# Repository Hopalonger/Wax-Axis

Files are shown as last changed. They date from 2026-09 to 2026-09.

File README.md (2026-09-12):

# Wax Axis

A fully automated IR ski/snowboard waxing machine, built as a college engineering project at Oregon State University. Wax Axis drives an IR waxer along a linear axis at a controlled, repeatable speed and pass count, so hot-waxing no longer depends on a human hand holding steady pressure and pace down the length of a ski or snowboard base.

## Background

This project started as a solution to a real bottleneck: as president of Oregon State's Ski and Snowboard Club, I help run free wax nights that typically get through 40–60 pairs of skis and boards in about two hours. Most of that time isn't spent waxing — it's spent scraping — but the waxing step itself is still slow and inconsistent when it's done by hand.
The club had already picked up a Mountainflow IR waxing iron, which works great except that it still has to be dragged across each base by hand at a slow, even pace to get good results. Wax Axis automates that motion.
The machine was originally built out of PVC pipe as a quick, cheap proof of concept, and has since been rebuilt on aluminum 2020 extrusion for rigidity and precision.

## Key Features

- **Automatic frame length detection** — the machine senses the length of the frame/travel automatically rather than requiring a manual endpoint setup
- **Iron speed and pass count control** — set how fast the waxer moves and how many passes it makes per run
- **Automated firmware updates** — OTA updates pushed wirelessly, no need to re-flash by cable
- **Full manual control** — jog and control the axis directly when you don't want an automated run
- **Wireless control via Wi-Fi and a web UI** — control the machine from a phone or laptop browser on the local network, no app required
- **Sensorless homing (StallGuard)** — homes itself using motor stall detection instead of physical limit switches
- **Relay-controlled waxer power** — the IR waxer is switched through a relay rather than staying on a dumb outlet

## Hardware Architecture

- **Frame:** 2020 aluminum extrusion rails with a 2020 gantry carriage (originally prototyped in PVC)
- **Motion:** [PD Stepper](https://www.sparkfun.com/pd-stepper.html) — the core of the whole system. It's an all-in-one, USB-PD-powered NEMA 17 driver/controller with a built-in ESP32-S3, a TMC2209 driver (StallGuard sensorless homing), and an AS5600 magnetic encoder for closed-loop position control — this one board is what handles motion control, homing, and the Wi-Fi/web UI.
- **Drive train:** GT2 10mm timing belt with matching drive and idler pulleys along the extrusion rail
- **Waxer:** IR (infrared) waxer mounted to the carriage as the heat source (purchased separately — a Mountainflow IR iron in this build)
- **I/O expansion:** Qwiic GPIO board over I2C — required for the additional inputs/outputs the project needs beyond the PD Stepper's native pins
- **Power control:** Relay board switches waxer power; power socket, cord, and switch assembly bring mains power into the electronics enclosure
- **Cable management:** Drag chains route wiring along the moving axis to prevent snagging and wear

## Getting Started

1. Assemble the frame from the 2020 extrusion and gantry hardware, and mount the GT2 belt and pulleys along the rail.
2. Wire the electronics enclosure: power entry (socket, cord, switch) → relay board → IR waxer; PD Stepper wired to the motor and belt drive; Qwiic GPIO board connected over the Qwiic/I2C bus.
3. Power on the machine and connect to its Wi-Fi captive portal to join it to your local network.
4. Open the machine's web UI in a browser on that network.
5. Let the machine auto-detect the frame/travel length, or home manually via sensorless homing (StallGuard — no limit switches needed).
6. Set your desired speed and pass count, or switch to full manual control, and run a pass.

## Bill of Materials

Rough parts and pricing for the core electronics/motion system (excludes the IR waxer itself, which is purchased separately — this build uses a Mountainflow IR waxing iron).

| Part | Qty | Link | Rough Price |
|---|---|---|---|
| PD Stepper (ESP32-S3 + TMC2209 + AS5600 closed-loop stepper driver/controller) | 1 | [SparkFun](https://www.sparkfun.com/pd-stepper.html) | $64.95 |
| Qwiic GPIO Board | 1 | [SparkFun](https://www.sparkfun.com/sparkfun-qwiic-gpio.html) | $7 |
| Qwiic Cable (flexible, 500mm) | 1 | [SparkFun](https://www.sparkfun.com/flexible-qwiic-cable-500mm.html) | $3 |
| Relay Board (4-channel, optocoupler isolated) | 1 | [Amazon](https://www.amazon.com/dp/B095YFJ69T) | $7 |
| GT2 Timing Belt, 10mm width, 5m length | 1 | [Amazon](https://www.amazon.com/dp/B078STSGSX) | ~$20 |
| GT2 Drive Pulley, 20T, 5mm bore (10mm belt) | 1+ | [Amazon](https://www.amazon.com/gt2-20t-pulley/s?k=gt2+20t+pulley) | ~$8 |
| GT2 Idler Pulley, 20T toothless, 5mm bore (10mm belt) | 1+ | [Amazon](https://www.amazon.com/gt2-20t-pulley/s?k=gt2+20t+pulley) | ~$8 |
| 2020 Extrusion | 1 | McMaster | $90 |
| Mounting Hardware (fasteners, misc.) | 1 | McMaster | $30 |
| 2020 Gantry Carriage | 1 | [Amazon](https://www.amazon.com/dp/B0DYNV76M3) | $23 |
| Power Socket Plug | 1 | [Amazon](https://www.amazon.com/dp/B0BZR7XDVM) | $9.50 |
| Power Cord | 1 | [Amazon](https://www.amazon.com/dp/B09VRLJD7J) | $6 |
| Power Switch | 1 | [Amazon](https://www.amazon.com/dp/B07RRY5MYZ) | $11 |
| Drag Chains | 1 | McMaster | $110 |

> The core electronics/motion stack (PD Stepper, Qwiic board + cable, relay, belt, and pulleys) comes in around $110–120, in line with the ~$150-in-parts figure for the electronics side of the build, excluding the IR waxer and frame materials.

### Final Design Changes to be made

**Hardware**
- Flip around electronics box plugs, or at least some of them
- Shrink the electronics box
- Update the electronics box to be mounted better
- Create some sort of better lock for the iron to go into — a screw or similar
- Create the final assembly with all of the parts in it

**Software**
- Create a way to manually set endpoints
- Create a way to add in saved speeds with labels for the button, such as "Snowboard," "Ski," "Black Topsheet Ski"

## Status

Active development, working through community and coursework feedback before open-sourcing the full design.

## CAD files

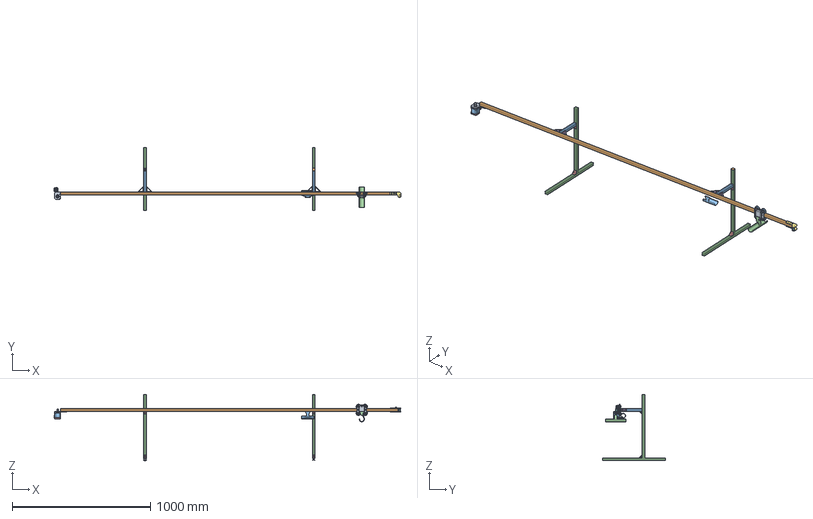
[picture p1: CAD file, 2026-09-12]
Hardware/Main Assembly.step
2506.8 x 457.2 x 479.7 mm
3684N14_Corrosion-Resistant Aluminum Gt Timing Belt Pulley
6627T231_Stepper Motor
3693N13_High-Strength Gt Timing Belt Idler Pulley
Motor Mount
5537T13_T-Slotted Framing
5537T044_T-Slotted Framing x 2
5537T895_T-Slotted Framing_1 x 3
5537T895_T-Slotted Framing
5537T518_T-Slotted Framing
5537T518_T-Slotted Framing_2 x 3
5537T518_T-Slotted Framing_1
5537T658_T-Slotted Framing x 4
Idler Holder Top
Idler Holder Bottom
Bushings
Gantry Plate
Bearing
T-Slot Roller Wheel
Bearing_1
T-Slot Roller Wheel_1
Bushings_1
Bushings_2
Bushings_3
Bearing_2
T-Slot Roller Wheel_2
Bearing_3
T-Slot Roller Wheel_3
91290A434_Black-Oxide Alloy Steel Socket Head Screw
90576A116_Medium-Strength Steel Nylon-Insert Locknut
90576A116_Medium-Strength Steel Nylon-Insert Locknut_1
90576A116_Medium-Strength Steel Nylon-Insert Locknut_2
90576A116_Medium-Strength Steel Nylon-Insert Locknut_3
91290A434_Black-Oxide Alloy Steel Socket Head Screw_1
91290A434_Black-Oxide Alloy Steel Socket Head Screw_2
91290A434_Black-Oxide Alloy Steel Socket Head Screw_3
90128A232_Zinc-Plated Alloy Steel Socket Head Screw
4976N25_T-Slotted Framing Fasteners
Wax Handle Mount V2
5537T14_T-Slotted Framing
Updated IR waxer Hook
Rotated Wax Handle

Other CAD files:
Hardware/Main Assembly.3mf
Hardware/Main Assembly.f3z

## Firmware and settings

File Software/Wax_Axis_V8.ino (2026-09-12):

/*
  Wax Axis V6 (Driver bring-up aligned to known-good V5)

  Fixes:
  - Uses settingsToJsonWithHoming() (exists in homing.h) instead of settingsToJson()
  - Uses waxStartPreheat() / waxStartRun(passes) (exists in wax_process.h)
  - PD CFG mapping + TMC UART setup identical to working V5 patterns
*/

#include <WiFi.h>
#include <ESPAsyncWebServer.h>
#include <AsyncTCP.h>
#include <Preferences.h>
#include <Wire.h>
#include <TMC2209.h>

#include "pins.h"
#include "encoder_as5600.h"
#include "settings.h"
#include "relay_io.h"
#include "motion.h"
#include "homing.h"
#include "wax_process.h"
#include "ota.h"

#include "ui_style.h"
#include "ui_operate.h"
#include "ui_config.h"
#include "ui_settings.h"
#include "ui_update.h"

// ===================== Web Server =====================
AsyncWebServer server(80);

// ===================== Driver =====================
TMC2209 stepper_driver;
HardwareSerial &serial_stream = Serial2;
static const long SERIAL_BAUD_RATE = 115200;

// ===================== Voltage read helpers (MATCH V5) =====================
static float VBusVoltage = 0.0f;
static const float VREF = 3.3f;
static const float DIV_RATIO = 0.1189427313f;

static inline String argOr(AsyncWebServerRequest *request, const char *name, const String &fallback) {
  if (request->hasParam(name, true)) return request->getParam(name, true)->value();
  return fallback;
}
static inline void sendOk(AsyncWebServerRequest *request, const String &msg = "OK") {
  request->send(200, "text/plain; charset=utf-8", msg);
}

// ===================== PD CFG pin mapping (EXACT V5) =====================
static inline void configureVoltagePins() {
  // NOTE: This is NOT binary; keep exactly as V5
  if (gSettings.setVoltage == "5") {
    digitalWrite(CFG1, HIGH);
    digitalWrite(CFG2, LOW);
    digitalWrite(CFG3, LOW);
  } else if (gSettings.setVoltage == "9") {
    digitalWrite(CFG1, LOW);
    digitalWrite(CFG2, LOW);
    digitalWrite(CFG3, LOW);
  } else if (gSettings.setVoltage == "12") {
    digitalWrite(CFG1, LOW);
    digitalWrite(CFG2, LOW);
    digitalWrite(CFG3, HIGH);
  } else if (gSettings.setVoltage == "15") {
    digitalWrite(CFG1, LOW);
    digitalWrite(CFG2, HIGH);
    digitalWrite(CFG3, HIGH);
  } else {  // "20"
    digitalWrite(CFG1, LOW);
    digitalWrite(CFG2, HIGH);
    digitalWrite(CFG3, LOW);
  }
}

static inline void configureDriverFromSettings() {
  // PD output selection
  configureVoltagePins();

  // TMC params
  int ms = gSettings.microsteps.toInt();
  if (ms <= 0) ms = 1;

  stepper_driver.setRunCurrent((uint8_t)gSettings.current.toInt());
  stepper_driver.setMicrostepsPerStep(ms);
  stepper_driver.setStallGuardThreshold((int8_t)gSettings.stallThreshold.toInt());

  // Standstill mode
  if (gSettings.standstillMode == "NORMAL") stepper_driver.setStandstillMode(stepper_driver.NORMAL);
  else if (gSettings.standstillMode == "FREEWHEELING") stepper_driver.setStandstillMode(stepper_driver.FREEWHEELING);
  else if (gSettings.standstillMode == "BRAKING") stepper_driver.setStandstillMode(stepper_driver.BRAKING);
  else if (gSettings.standstillMode == "STRONG_BRAKING") stepper_driver.setStandstillMode(stepper_driver.STRONG_BRAKING);
  else stepper_driver.setStandstillMode(stepper_driver.NORMAL);

  // Motion layer depends on routine speed
  motionSetRoutineSpeedUnits((int)gSettings.routineSpeedUnits);
}

static inline String readPGState() {
  return (digitalRead(PG) == LOW) ? "Power Good" : "Power Bad";
}

static inline String readVoltage() {
  int ADCValue = analogRead(VBUS);
  VBusVoltage = ADCValue * (VREF / 4096.0f) / DIV_RATIO;
  return String(VBusVoltage, 2) + "V";
}

static inline String readEncoderPos() {
  return String(encoderGetCounts());
}

static inline String readTMCStatus() {
  if (stepper_driver.hardwareDisabled()) return "Hardware Disabled";
  TMC2209::Status st = stepper_driver.getStatus();
  if (st.over_temperature_shutdown) return "Over Temp Shutdown";
  if (st.over_temperature_warning) return "Over Temp Warning";
  return "No Errors";
}

void setup() {
  // --------- Pin bring-up (MATCH V5 ordering/levels) ---------
  pinMode(PG, INPUT);

  pinMode(CFG1, OUTPUT);
  pinMode(CFG2, OUTPUT);
  pinMode(CFG3, OUTPUT);

  pinMode(LED1, OUTPUT);
  pinMode(LED2, OUTPUT);

  pinMode(STEP, OUTPUT);
  pinMode(DIR, OUTPUT);
  digitalWrite(STEP, LOW);

  pinMode(MS1, OUTPUT);
  pinMode(MS2, OUTPUT);
  digitalWrite(MS1, LOW);
  digitalWrite(MS2, LOW);

  pinMode(TMC_EN, OUTPUT);
  digitalWrite(TMC_EN, LOW);  // board enable pin (V5)

  pinMode(DIAG, INPUT);
  pinMode(VBUS, INPUT);

  // ADC setup
  analogReadResolution(12);
  analogSetPinAttenuation(VBUS, ADC_11db);

  Serial.begin(115200);
  delay(200);
  Serial.println("\nWax Axis V6 (V5-aligned bring-up) boot...");

  // I2C bus
  Wire.begin(I2C_SDA, I2C_SCL);
  delay(10);

  // Encoder + relay
  encoderBegin();
  bool relayOk = relayBegin();
  Serial.println(relayOk ? "Relay expander OK" : "Relay expander MISSING");
  relaySet(false);

  // Load settings early
  settingsLoad();

  // --------- TMC2209 UART bring-up (EXACT V5 signature) ---------
  stepper_driver.setup(serial_stream, SERIAL_BAUD_RATE, TMC2209::SERIAL_ADDRESS_0, TMC_RX, TMC_TX);
  stepper_driver.enableAutomaticCurrentScaling();
  stepper_driver.enableStealthChop();
  stepper_driver.setCoolStepDurationThreshold(5000);
  stepper_driver.disable();

  // Apply PD voltage + driver params
  configureDriverFromSettings();

  // Motion/homing init
  motionBegin();
  homingLoadState();
  waxStop();

  // WiFi AP
  WiFi.mode(WIFI_AP);
  WiFi.softAP(AP_SSID, AP_PASS);
  Serial.print("AP IP: ");
  Serial.println(WiFi.softAPIP());

  // --------- Pages ---------
  server.on("/", HTTP_GET, [](AsyncWebServerRequest *request) {
    request->send_P(200, "text/html; charset=utf-8", UI_OPERATE_HTML);
  });
  server.on("/setup", HTTP_GET, [](AsyncWebServerRequest *request) {
    request->send_P(200, "text/html; charset=utf-8", UI_CONFIG_HTML);
  });
  server.on("/config", HTTP_GET, [](AsyncWebServerRequest *request) {
    request->send_P(200, "text/html; charset=utf-8", UI_CONFIG_HTML);
  });
  server.on("/settings", HTTP_GET, [](AsyncWebServerRequest *request) {
    request->send_P(200, "text/html; charset=utf-8", UI_SETTINGS_HTML);
  });
  server.on("/update", HTTP_GET, [](AsyncWebServerRequest *request) {
    request->send_P(200, "text/html; charset=utf-8", UI_UPDATE_HTML);
  });
  server.on("/style.css", HTTP_GET, [](AsyncWebServerRequest *request) {
    request->send_P(200, "text/css; charset=utf-8", UI_STYLE_CSS);
  });

  // --------- Stats ---------
  server.on("/powergood", HTTP_GET, [](AsyncWebServerRequest *request) {
    request->send(200, "text/plain; charset=utf-8", readPGState());
  });
  server.on("/voltage", HTTP_GET, [](AsyncWebServerRequest *request) {
    request->send(200, "text/plain; charset=utf-8", readVoltage());
  });
  server.on("/position", HTTP_GET, [](AsyncWebServerRequest *request) {
    request->send(200, "text/plain; charset=utf-8", readEncoderPos());
  });
  server.on("/status", HTTP_GET, [](AsyncWebServerRequest *request) {
    request->send(200, "text/plain; charset=utf-8", readTMCStatus());
  });

  // IMPORTANT: V6 uses this helper (implemented in homing.h)
  server.on("/settingsjson", HTTP_GET, [](AsyncWebServerRequest *request) {
    request->send(200, "application/json; charset=utf-8", settingsToJsonWithHoming());
  });

  server.on("/homingstatus", HTTP_GET, [](AsyncWebServerRequest *request) {
    request->send(200, "application/json; charset=utf-8", homingStatusJson());
  });

  server.on("/waxstatus", HTTP_GET, [](AsyncWebServerRequest *request) {
    request->send(200, "application/json; charset=utf-8", waxStatusJson());
  });

  // --------- Actions ---------
  server.on("/stop", HTTP_POST, [](AsyncWebServerRequest *request) {
    waxStop();
    motionStopAll();
    relaySet(false);
    sendOk(request, "Stopped");
  });

  server.on("/reset", HTTP_POST, [](AsyncWebServerRequest *request) {
    homingCancel();
    waxReset();
    motionStopAll();
    relaySet(false);
    sendOk(request, "Reset complete");
  });

  server.on("/heater", HTTP_POST, [](AsyncWebServerRequest *request) {
    String v = argOr(request, "heater", "");
    if (v.length() == 0) v = argOr(request, "on", "0");
    bool on = (v.toInt() != 0);
    relaySet(on);
    sendOk(request, relayIsOn() ? "Heater ON" : "Heater OFF");
  });

  server.on("/setopspeed", HTTP_POST, [](AsyncWebServerRequest *request) {
    String v = argOr(request, "routinespeed", String((long)gSettings.routineSpeedUnits));
    long rs = v.toInt();
    if (rs < 5) rs = 5;
    if (rs > 200) rs = 200;
    gSettings.routineSpeedUnits = rs;
    settingsSave();
    motionSetRoutineSpeedUnits((int)rs);
    sendOk(request, "OK");
  });

  server.on("/returnhome", HTTP_POST, [](AsyncWebServerRequest *request) {
    waxReturnToParkNow();
    sendOk(request, "Returning to Park");
  });

  server.on("/homing", HTTP_POST, [](AsyncWebServerRequest *request) {
    if (!motionCanAcceptCommand()) {
      request->send(409, "text/plain; charset=utf-8", "Power Bad / Disabled");
      return;
    }
    bool ok = homingStartAsync();
    request->send(200, "application/json; charset=utf-8", ok ? "{\"ok\":true}" : "{\"ok\":false,\"msg\":\"already running\"}");
  });

  // FIX: real function names from wax_process.h
  server.on("/preheat", HTTP_POST, [](AsyncWebServerRequest *request) {
    bool ok = waxStartPreheat();
    request->send(ok ? 200 : 409, "text/plain; charset=utf-8", ok ? "Preheat started" : "Preheat rejected");
  });

  // UI posts: passes=#
  server.on("/run", HTTP_POST, [](AsyncWebServerRequest *request) {
    uint32_t passes = 1;
    if (request->hasParam("passes", true)) passes = (uint32_t)request->getParam("passes", true)->value().toInt();
    if (passes < 1) passes = 1;
    if (passes > 50) passes = 50;  // safety clamp

    bool ok = waxStartRun(passes);
    request->send(ok ? 200 : 409, "text/plain; charset=utf-8", ok ? "Run started" : "Run rejected");
  });

  // Setup page save
  server.on("/save", HTTP_POST, [](AsyncWebServerRequest *request) {
    gSettings.driverEnabled = request->hasParam("enabled1", true);

    gSettings.setVoltage = argOr(request, "setvoltage", gSettings.setVoltage);
    gSettings.microsteps = argOr(request, "microsteps", gSettings.microsteps);
    gSettings.current = argOr(request, "current", gSettings.current);
    gSettings.stallThreshold = argOr(request, "stall_threshold", gSettings.stallThreshold);
    gSettings.standstillMode = argOr(request, "standstill_mode", gSettings.standstillMode);

    gSettings.homingBackoffCounts = argOr(request, "home_backoff", String(gSettings.homingBackoffCounts)).toInt();
    gSettings.gotoTolCounts = argOr(request, "goto_tol", String(gSettings.gotoTolCounts)).toInt();

    settingsSave();
    configureDriverFromSettings();

    request->redirect("/setup");
  });

  // Settings page save (process parameters)
  server.on("/savesettings", HTTP_POST, [](AsyncWebServerRequest *request) {
    // UI provides percent… firmware stores multiplier
    int preheatPct = argOr(request, "preheat_pct", String((int)lroundf(gSettings.preheatMult * 100.0f))).toInt();
    if (preheatPct < 100) preheatPct = 100;
    if (preheatPct > 500) preheatPct = 500;
    gSettings.preheatMult = (float)preheatPct / 100.0f;

    gSettings.returnSpeedPct = argOr(request, "return_pct", String(gSettings.returnSpeedPct)).toInt();
    gSettings.heaterDelayMs = argOr(request, "heater_delay", String(gSettings.heaterDelayMs)).toInt();

    gSettings.edgeKeepoffCounts = argOr(request, "edge_keepoff", String(gSettings.edgeKeepoffCounts)).toInt();
    gSettings.parkOffsetCounts = argOr(request, "park_offset", String(gSettings.parkOffsetCounts)).toInt();
    gSettings.homingSpeedUnits = argOr(request, "homing_speed", String(gSettings.homingSpeedUnits)).toInt();
    gSettings.homingTimeoutMs = (uint32_t)argOr(request, "homing_timeout", String(gSettings.homingTimeoutMs)).toInt();

    String hs = argOr(request, "home_side", gSettings.homeSideIsMin ? "min" : "max");
    gSettings.homeSideIsMin = (hs == "min");

    settingsSave();

    // If we already know ends, recompute park/op window immediately.
    homingRecomputeDerived();

    request->redirect("/settings");
  });
  // OTA
  server.on("/updatefw", HTTP_POST, handleFwUpdateRequest, handleFwUpload);

  server.onNotFound([](AsyncWebServerRequest *request) {
    request->send(404, "text/plain; charset=utf-8", "Not found");
  });


  // ===================== Manual motion controls (Operate page) =====================
  // - slider: signed velocity in UI units (-400..400)
  // - positionControl: 1..4 jog buttons
  server.on("/manual", HTTP_POST, [](AsyncWebServerRequest *request) {
    if (request->hasParam("slider", true)) {
      int v = request->getParam("slider", true)->value().toInt();
      motionSetSlider(v);
    }
    if (request->hasParam("positionControl", true)) {
      int which = request->getParam("positionControl", true)->value().toInt();
      motionJog(which);
    }
    request->send(200, "text/plain", "OK");
  });

  server.on("/goto", HTTP_POST, [](AsyncWebServerRequest *request) {
    if (!request->hasParam("target", true)) {
      request->send(400, "text/plain", "Missing target");
      return;
    }
    long t = request->getParam("target", true)->value().toInt();
    if (!motionCanAcceptCommand()) {
      request->send(409, "text/plain", "Power Bad / Disabled");
      return;
    }
    motionGoto(t);
    request->send(200, "text/plain", "OK");
  });

  server.on("/gotostatus", HTTP_GET, [](AsyncWebServerRequest *request) {
    request->send(200, "text/plain", motionGotoStatus());
  });

  server.begin();

  motionStopAll();
  relaySet(false);

  digitalWrite(LED1, HIGH);
  delay(120);
  digitalWrite(LED1, LOW);

  Serial.println("Wax Axis web server started.");
}

void loop() {
  encoderTask();
  motionEnableTask();
  motionControlTask();
  homingServiceTask();
  waxTask();
}

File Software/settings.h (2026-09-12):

#pragma once
#include <Arduino.h>
#include <Preferences.h>

struct WaxAxisSettings {
  // Driver / low-level
  bool   driverEnabled = true;
  String setVoltage    = "5";     // default to 5V so you can run from laptop USB power
  String microsteps    = "32";
  String current       = "10";
  String stallThreshold= "63";
  String standstillMode= "NORMAL";

  // Motion tolerances (encoder counts)
  long gotoTolCounts   = 3;
  long ppTolCounts     = 6;

  // Homing
  long     homingBackoffCounts = 200;
  long     homingSpeedUnits    = 150;
  uint32_t homingTimeoutMs     = 120000;  // user-adjustable now
  bool     homeSideIsMin       = true;    // min end becomes "home"

  // Rail geometry (user-facing)
  long edgeKeepoffCounts = 800;   // how far from each physical end we operate
  long parkOffsetCounts  = 1000;  // additional offset from the HOME operating edge

  // Operating speed (UI units, 5..200, linear)
  long routineSpeedUnits = 100;

  // Wax routine
  float preheatMult     = 2.0f;
  int   returnSpeedPct  = 200;
  int   heaterDelayMs   = 500;
};

static Preferences gPrefs;
static WaxAxisSettings gSettings;

// Increment this when you change preference semantics/defaults.
static const uint32_t SETTINGS_SCHEMA_VER = 3;

static inline void settingsMigrateIfNeeded() {
  gPrefs.begin("settings", false);

  uint32_t ver = gPrefs.getUInt("schema", 0);
  if (ver < SETTINGS_SCHEMA_VER) {
    // ---- Migration rules ----
    // v2: default PD voltage should be 5V (previous builds often left 20V in NVS).
    // Only force it on migration so users can still change it later.
    gPrefs.putString("voltage", "5");

    // v2: ensure standstill strings are consistent with UI options
    // (UI uses FREEWHEELING; driver mapping accepts both, but keep it neat).
    String ssm = gPrefs.getString("standstillMode", "NORMAL");
    ssm.trim(); ssm.toUpperCase();
    if (ssm == "FREEWHEEL") ssm = "FREEWHEELING";
    gPrefs.putString("standstillMode", ssm);

    // v3: add configurable homing speed default.
    if (ver < 3) {
      gPrefs.putLong("homingSpeed", 150);
    }

    gPrefs.putUInt("schema", SETTINGS_SCHEMA_VER);
  }

  // First-run init (keep separate from schema so we can migrate later)
  bool inited = gPrefs.getBool("init", false);
  if (!inited) {
    gPrefs.putBool("init", true);

    gPrefs.putUInt("schema", SETTINGS_SCHEMA_VER);

    gPrefs.putBool  ("driverEnabled", gSettings.driverEnabled);
    gPrefs.putString("voltage", gSettings.setVoltage);
    gPrefs.putString("microsteps", gSettings.microsteps);
    gPrefs.putString("current", gSettings.current);
    gPrefs.putString("stallThreshold", gSettings.stallThreshold);
    gPrefs.putString("standstillMode", gSettings.standstillMode);

    gPrefs.putLong("gotoTol", gSettings.gotoTolCounts);
    gPrefs.putLong("ppTol", gSettings.ppTolCounts);

    gPrefs.putLong("homeBackoff", gSettings.homingBackoffCounts);
    gPrefs.putLong("homingSpeed", gSettings.homingSpeedUnits);
    gPrefs.putUInt("homeTimeout", gSettings.homingTimeoutMs);
    gPrefs.putBool("homeIsMin", gSettings.homeSideIsMin);

    gPrefs.putLong("edgeKeepoff", gSettings.edgeKeepoffCounts);
    gPrefs.putLong("parkOffset", gSettings.parkOffsetCounts);

    gPrefs.putLong("routineSpeed", gSettings.routineSpeedUnits);

    gPrefs.putFloat("preheatMult", gSettings.preheatMult);
    gPrefs.putInt  ("returnPct", gSettings.returnSpeedPct);
    gPrefs.putInt  ("heaterDelayMs", gSettings.heaterDelayMs);
  }

  gPrefs.end();
}
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

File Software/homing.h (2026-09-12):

#pragma once
#include <Arduino.h>
#include <Preferences.h>
#include <TMC2209.h>

#include "pins.h"
#include "settings.h"
#include "encoder_as5600.h"
#include "motion.h"

// Provided by main .ino
extern TMC2209 stepper_driver;

static Preferences gHomePrefs;

// DIAG behavior (adjust if your DIAG polarity differs)
static const bool DIAG_ACTIVE_HIGH = true;
static const int  DIAG_IRQ_MODE    = RISING;

static volatile bool g_diagHit = false;
static volatile bool g_homeAbort = false;

static inline void IRAM_ATTR diag_isr() {
  g_diagHit = true;
}

static inline void clearDiag() {
  g_diagHit = false;
  (void)digitalRead(DIAG);
}

static inline bool homingAbortRequested() {
  return g_homeAbort;
}


struct HomingState {
  bool running = false;
  bool done    = false;
  bool error   = false;
  String msg   = "idle";

  // physical ends (encoder counts)
  long endMin  = 0;
  long endMax  = 0;

  // derived window + park
  long opMin   = 0;
  long opMax   = 0;
  long parkPos = 0;

  bool validEnds = false;
};

static HomingState gHome;
static portMUX_TYPE gHomeMux = portMUX_INITIALIZER_UNLOCKED;

// ===== Helpers =====
static inline bool diagStable(uint32_t assertMs) {
  static uint32_t sinceMs = 0;
  bool diag = (digitalRead(DIAG) == (DIAG_ACTIVE_HIGH ? HIGH : LOW));
  if (diag) {
    if (sinceMs == 0) sinceMs = millis();
    if (millis() - sinceMs >= assertMs) return true;
  } else {
    sinceMs = 0;
  }
  return false;
}

static inline int32_t rampVelToward(int32_t vNow, int32_t vTarget, int32_t dvMaxPerTick) {
  if (vTarget > vNow) {
    int32_t d = vTarget - vNow;
    if (d > dvMaxPerTick) d = dvMaxPerTick;
    return vNow + d;
  } else {
    int32_t d = vNow - vTarget;
    if (d > dvMaxPerTick) d = dvMaxPerTick;
    return vNow - d;
  }
}

static bool runUntilDiagVelRamped(int32_t vTargetUnits,
                                 uint32_t timeoutMs,
                                 uint32_t diagAssertMs,
                                 int32_t rampUnitsPerTick,
                                 uint32_t tickMs)
{
  clearDiag();
  int32_t vNow = 0;
  stepper_driver.moveAtVelocity(unitsToDriverVel(0));

  const uint32_t STALL_WINDOW_MS = 250;
  const long STALL_MIN_DELTA_COUNTS = 4;
  const int32_t STALL_MONITOR_MIN_SPEED = 25;

  encoderReadNow();
  long stallWindowStartPos = encoderGetCounts();
  uint32_t startMs = millis();
  uint32_t lastTick = startMs;
  uint32_t stallWindowStartMs = startMs;

  while (true) {
    if (homingAbortRequested()) {
      stepper_driver.moveAtVelocity(unitsToDriverVel(0));
      return false;
    }
    if (g_diagHit || diagStable(diagAssertMs)) {
      stepper_driver.moveAtVelocity(unitsToDriverVel(0));
      return true;
    }
    if ((uint32_t)(millis() - startMs) >= timeoutMs) {
      stepper_driver.moveAtVelocity(unitsToDriverVel(0));
      return false;
    }

    encoderReadNow();
    long nowPos = encoderGetCounts();
    uint32_t now = millis();

    if ((uint32_t)(now - stallWindowStartMs) >= STALL_WINDOW_MS) {
      long traveled = labs_long(nowPos - stallWindowStartPos);
      if (abs(vNow) >= STALL_MONITOR_MIN_SPEED && traveled <= STALL_MIN_DELTA_COUNTS) {
        stepper_driver.moveAtVelocity(unitsToDriverVel(0));
        return true;
      }
      stallWindowStartPos = nowPos;
      stallWindowStartMs = now;
    }

    if (now - lastTick >= tickMs) {
      lastTick = now;
      vNow = rampVelToward(vNow, vTargetUnits, rampUnitsPerTick);
      stepper_driver.moveAtVelocity(unitsToDriverVel(vNow));
    }
    vTaskDelay(1);
  }
}

static bool backoffByEncoderDeltaRamped(int32_t vTargetUnits,
                                       long backoffCounts,
                                       uint32_t timeoutMs,
                                       int32_t rampUnitsPerTick,
                                       uint32_t tickMs)
{
  encoderReadNow();
  long startPos = encoderGetCounts();
  int32_t vNow = 0;
  stepper_driver.moveAtVelocity(unitsToDriverVel(0));

  uint32_t startMs = millis();
  uint32_t lastTick = startMs;

  while (true) {
    if (homingAbortRequested()) {
      stepper_driver.moveAtVelocity(unitsToDriverVel(0));
      return false;
    }
    encoderReadNow();
    long nowPos = encoderGetCounts();
    if (labs_long(nowPos - startPos) >= backoffCounts) {
      stepper_driver.moveAtVelocity(unitsToDriverVel(0));
      return true;
    }
    if ((uint32_t)(millis() - startMs) >= timeoutMs) {
      stepper_driver.moveAtVelocity(unitsToDriverVel(0));
      return false;
    }
    uint32_t now = millis();
    if (now - lastTick >= tickMs) {
      lastTick = now;
      vNow = rampVelToward(vNow, vTargetUnits, rampUnitsPerTick);
      stepper_driver.moveAtVelocity(unitsToDriverVel(vNow));
    }
    vTaskDelay(1);
  }
}

static bool homeOneSideRamped(int32_t velTowardFastUnits,
                             int32_t velTowardSlowUnits,
                             int32_t velAwayUnits,
                             long backoffCounts,
                             uint32_t settleMs,
                             uint32_t timeoutMsTotal,
                             uint32_t diagAssertMs,
                             int32_t rampUnitsPerTick,
                             uint32_t tickMs,
                             long &posAtHitOut)
{
  uint32_t tFast = timeoutMsTotal / 2;
  uint32_t tBack = timeoutMsTotal / 4;
  uint32_t tSlow = timeoutMsTotal / 4;

  if (!runUntilDiagVelRamped(velTowardFastUnits, tFast, diagAssertMs, rampUnitsPerTick, tickMs)) return false;
  vTaskDelay(pdMS_TO_TICKS(settleMs));

  if (!backoffByEncoderDeltaRamped(velAwayUnits, backoffCounts, tBack, rampUnitsPerTick, tickMs)) return false;
  vTaskDelay(pdMS_TO_TICKS(settleMs));

  if (!runUntilDiagVelRamped(velTowardSlowUnits, tSlow, diagAssertMs, rampUnitsPerTick, tickMs)) return false;
  vTaskDelay(pdMS_TO_TICKS(settleMs));

  encoderReadNow();
  posAtHitOut = encoderGetCounts();
  return true;
}

static inline void homingComputeDerivedLocked() {
  if (!gHome.validEnds) return;

  long endMin = gHome.endMin;
  long endMax = gHome.endMax;

  long keep = gSettings.edgeKeepoffCounts;
  long opMin = endMin + keep;
  long opMax = endMax - keep;
  if (opMax < opMin) {
    // keepoff too large; collapse safely
    long mid = (endMin + endMax) / 2;
    opMin = mid;
    opMax = mid;
  }

  long park;
  if (gSettings.homeSideIsMin) {
    park = opMin + gSettings.parkOffsetCounts;
    if (park > opMax) park = opMax;
  } else {
    park = opMax - gSettings.parkOffsetCounts;
    if (park < opMin) park = opMin;
  }

  gHome.opMin = opMin;
  gHome.opMax = opMax;
  gHome.parkPos = park;
}

static inline void homingSaveState() {
  if (!gHome.validEnds) return;
  gHomePrefs.begin("homing", false);
  gHomePrefs.putBool("valid", true);
  gHomePrefs.putLong("endMin", gHome.endMin);
  gHomePrefs.putLong("endMax", gHome.endMax);
  gHomePrefs.end();
}
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

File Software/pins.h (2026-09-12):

#pragma once
#include <Arduino.h>

// ===================== Access Point =====================
static const char *AP_SSID = "Wax Axis";
static const char *AP_PASS = "";

// ===================== I2C (ESP32-S3) =====================
#define I2C_SDA 8
#define I2C_SCL 9

// ===================== Pin Defines (PD Stepper board) =====================
#define TMC_EN 21
#define STEP   5
#define DIR    6
#define MS1    1
#define MS2    2
#define SPREAD 7
#define TMC_TX 17
#define TMC_RX 18
#define DIAG   16
#define INDEX  11

#define PG   15
#define CFG1 38
#define CFG2 48
#define CFG3 47

#define VBUS 4
#define LED1 10
#define LED2 12
#define SW1  35
#define SW2  36
#define SW3  37
#define AUX1 14
#define AUX2 13
